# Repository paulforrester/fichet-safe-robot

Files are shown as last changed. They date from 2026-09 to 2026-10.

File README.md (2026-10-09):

# Fichet-Bauche "Complice" Safe — Combination Robot

> **Revision 2026-10-09.1** · all four drivers on the RAMPS (key in E0); UART pigtail replaces the hub board · log: `docs/revisions.md`

An automated device to determine the combination of an unmarked
Fichet-Bauche "Complice" safe found in the house at 6 Rue du Mulet,
Bordeaux. The project spans three phases: mechanical (tube-socket
coupler and drive), electrical (motor/servo control circuitry), and
firmware/code (dial indexing and combination search).

## Status

Mechanical phase. Tooth geometry is **CLOSED** (see `docs/decisions.md`
for how we got here):

| Dimension | Value | Status |
|---|---|---|
| Tooth height (radial, root→tip) | 2.00 mm | **locked in** — see `docs/decisions.md` |
| Tooth width (tangential) | 1.04 mm | **locked in** |
| Tooth depth (axial, into socket) | 5.0 mm | measured directly off the real key |
| Tip diameter | 7.73 mm (measured), 7.38mm printed (0.35mm clearance) | working |
| Collar diameter | 11.75 mm | confirmed, clears the ~12mm door recess |

Housings: the **dial unit v2** (`cad/dial_unit_housing.scad`, geared, on 608
bearings — door-pattern test passed on the real door) and the **key turner v1**
(`cad/key_turner_housing.scad`, slotted cap over the key's bow, motor on the key
axis — print `print_key_fit_test.scad` first). Both attach to the door with
22mm rubber-coated M4 pot magnets (6 + 3) held by printed retainers
(`print_magnet_retainer.scad`) — pull-test one on the door when they arrive. See `docs/housing_decisions.md` and `control/sequence.md`.

Electronics ordering is done — four orders placed 2026-09-29 cover
essentially the full `docs/bom.md`, tracked there against every line.

**How to build and run it:** `docs/manual.md` (mechanical and electrical
assembly, building and uploading the firmware, operating and monitoring).

## Repo layout

- `CLAUDE.md` — context and working rules for Claude sessions (cloud or
  local): project facts, decisions, open issues, how Paul works.
- `cad/` — OpenSCAD source for 3D-printed parts.
  - `tube_socket_test_key.scad` — the confirmed spline/tooth geometry,
    parametric (tooth height, width, and an engraved label are all
    top-level variables — see the file header for CLI override examples).
  - `common_mounts.scad` — shared NEMA17 bolt pattern, rubber-magnet
    mount (`rmag_*`), and D-shaft coupler-bore modules, used by both housings below.
  - `dial_unit_housing.scad` / `key_turner_housing.scad` — the two
    mounting housings (see `docs/housing_decisions.md`). The dial unit is
    v2 (geared); `dial_unit_assembled.scad` shows it assembled and the
    `print_*.scad` wrappers export each printable part.
  - `cad/tools/` — `dial_layout_check.py` (clearances, gear mesh, axial
    stack, read straight from the SCAD) and `dial_interference_check.py`
    (3D overlap check of the whole assembly through its range of motion).
  - `cad/sketchup/` — the build script for a SketchUp review model of the
    dial unit (run through the SketchUp connector; the SCAD files are what
    gets printed).
  - `cad/renders/` holds reference renders and STLs of specific
    iterations.
- `docs/` — dimensional decisions (`decisions.md` for the test key,
  `housing_decisions.md` for the housings), the bill of materials
  (`bom.md`, tracked against actual orders), terminology reference, and
  reference photos (`docs/photos/`).
- `control/` — control architecture and operating sequence
  (`sequence.md`), the wiring harness (`wiring.md`, diagrams in
  `control/harness/`, including the printable `schematic.pdf`), the firmware (`control/firmware/`), the bench
  bring-up plan (`bringup.md`) and the lock research (`lock_research.md`).

## Terminology

Tooth dimensions are described consistently as WIDTH (tangential),
HEIGHT (radial), DEPTH (axial into the socket) — see
`docs/tooth_terms_diagram.png`.

## Next steps

- Bench-fit the v0.1 housings once printed; confirm the placeholder
  dial-hole spacing and key-bow clamp range against the real door/key
  (see `docs/housing_decisions.md`'s "Bench-fit TODO").
- Dial unit v2 (geared, 608 bearings — see `docs/housing_decisions.md`):
  print the door-pattern test (`cad/print_dial_pattern_test.scad`) and the
  three gear-shafts first, and check them on the real door, before the
  big parts. Springs ordered (arriving 2026-10-07).
- Wiring harness designed (`control/wiring.md`; **revision 2026-10-08.1**:
  all four drivers on the RAMPS, the key in the E0 socket, no remote board
  or signal cable); firmware written and host-tested (`control/firmware/`,
  v0.4); next: the bench bring-up (`control/bringup.md`).

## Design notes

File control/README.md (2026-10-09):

# Control (motors, drivers, wiring, firmware)

> **Revision 2026-10-09.1** · key driver on the RAMPS E0 socket; UART pigtail · log: `../docs/revisions.md`

- `sequence.md` — control architecture and the operating sequence (seat,
  home, learn the key's stop angle, the 8,000-combination loop, false sets),
  plus what the firmware decided on top of it.
- `wiring.md` — the wiring harness: pin map, driver jumpers and UART
  addresses (all four drivers on the RAMPS, key in E0), the UART pigtail
  (the UART junction), the key motor cable, motor currents, power-up
  order, shopping list, with sources.
- `harness/ramps_and_uart.md` — one bench sheet of everything fitted to the
  RAMPS, and the UART pigtail.
- `harness/` — the printable schematic, WireViz harness diagram, Graphviz
  overview and the UART pigtail drawing (sources + rendered SVG/PNG).
- `firmware/` — Arduino Mega sketch (TMCStepper), its plain-C++ core with
  host tests against a simulated lock, and the serial logger. See
  `firmware/README.md`.
- `bringup.md` — bench bring-up in seven stages, with what to send back.
- `lock_research.md` — does the Complice relock or lock out? (No evidence of
  an attempt lockout; a relocker fires on attack.)

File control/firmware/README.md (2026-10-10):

# Firmware — Fichet safe robot (Mega 2560 + RAMPS 1.4 + 4 × TMC2209)

> **Revision 2026-10-09.1** · key driver on the RAMPS E0 socket; firmware v0.4 (unchanged by 2026-10-08.2) · log: `../../docs/revisions.md`

Implements the sequence in `control/sequence.md` on the pin map in
`control/wiring.md`. Bring it up on the bench with `control/bringup.md`.

## v0.4 (2026-10-08, project revision 2026-10-08.1): key driver on RAMPS E0

The key's TMC2209 moved from a remote board at the key turner to the RAMPS
**E0** socket (`control/wiring.md`, log 2026-10-08). For the firmware:
- `pins.h`: key STEP **D26**, DIR **D28**, EN **D24** (Marlin `pins_RAMPS.h`
  E0_STEP/DIR/ENABLE); DIAG stays on **D19** (Z_MAX S).
- The key is now an ordinary axis: direction from its DIR pin and enable from
  its EN pin, like the dials. Gone: `setKeyShaft()` (GCONF.shaft written and
  read back before each key move), the TOFF = 0 disable, and the `DIR` error
  that reported a shaft read-back failure.
- **Safer at power-up**: RAMPS pulls every EN line high (10 kΩ), so the key
  driver now stays off until the firmware enables it. Before, its EN was tied
  low and it switched on with 12 V at its pot current.
- Verified: host tests 53/53 (~36,500 checks), logger tests 3/3, AVR build
  52.1 KB flash. Not run on hardware.

## What it does

1. **Session start** (on `start`, `resume`, or the button; ~40 s), in order:
   - ping all four drivers over UART (version 0x21, right address) and
     configure them;
   - home the key against its rest stop (searching up to 180°: the key stays
     wherever it was left);
   - **calibrate the key** (see Calibration below);
   - seat the dials: slow, bounded 1/8 turn clockwise. The dials turn
     clockwise without limit, so this never meets a stop;
   - **calibrate each dial** with one free clockwise turn;
   - home each dial anticlockwise on its stop, in two passes that must agree,
     and park it on its first click;
   - learn the key's stop angle **N** (3 tries, median, spread checked).
2. **Attempt loop** over the 8,000 combinations in serpentine order: each
   attempt moves **one dial by one position**, never wraps a dial, turns the
   key to N + 15°, and logs the **actual angle reached**. It classifies the
   attempt (clean / false set / success / early), retracts the key to its
   rest stop, and saves progress to EEPROM.
3. **Every 200 attempts, a re-check**: re-home every dial (the home must be
   where the step count says it is) and re-learn N at the last clean fail.
   If anything moved, it stops, **rewinds to the last good re-check**, and
   asks for a re-seat.
4. **Success** (key gets ≥ N + 10°): stops, holds the key where it got to, and
   prints the combination as positions 1–20: clicks counted clockwise from
   each dial's stop (there are no marks on the door). The success is saved in
   EEPROM. The key stays turned after `release` (it doesn't spring back), so
   take the key turner off and pull the key to open the door, as the manual
   says.
5. **Resumable**: progress is in EEPROM. After a power cut or a re-seat,
   `resume` (or the button) redoes the session start and continues from the
   last re-checked index (≤ 200 attempts redone). A pause runs a re-check
   first, so a resume after a pause loses nothing.

## Calibration (Paul's suggestion, 2026-10-06)

The robot measures its own StallGuard thresholds and finds the clicks,
instead of relying on hand-tuned numbers. The datasheet recommends this kind
of in-application threshold rather than a fixed one (§11.4, p. 59).

- **Each dial**: one free turn clockwise (1¼ turns with the ramps). The
  dials turn clockwise without limit, so nothing is pressed. Every
  cruise-speed SG_RESULT reading is binned by its place within a click (20
  full steps = 18°).
  - **Threshold**: the lowest bin mean is the dial's heaviest free-running
    load. SGTHRS is set so a stall reads at **50 %** of it
    (`CFG_SG_CAL_PCT`; stall = SG_RESULT ≤ 2·SGTHRS, datasheet §5.3).
  - **Clicks**: their ripple has an 18° period, and its fundamental gives
    where the clicks are. Model: turning clockwise, the click spring helps
    just before a notch (SG highest) and resists just after (SG lowest), so
    the notch is a quarter click after the SG peak. After homing, position 1
    is the first click at least 3 full steps clockwise of the stop. Later
    sessions keep the same numbering, using the offset stored in EEPROM.
  - If the ripple is too weak to trust (amplitude < 3, or < 2× the
    residual), it falls back to `CFG_HOME_OFFSET_x` and says so.
- **Key**: from rest, 60° clockwise (its stop is at ~100°); median SG →
  threshold. It then goes back to rest by stalling on the rest stop **with
  the new threshold**, which proves the threshold works.
- The last calibration is kept in EEPROM. The next session needs it for its
  very first move (homing the key) before it re-calibrates.
- `calibrate` does all of this as a separate step and prints `CAL` /
  `OFFSET` lines. Run it once, with the key turned back to its start by hand.
  `set autocal 0` / `set detentcal 0` switch either part off (then `sgX` /
  `offX` are used as set).
- **ASSUMPTIONS to check on the bench** (`control/bringup.md` stages 3–4):
  - that 50 % sits safely between free running and a stall;
  - that the click ripple is visible in SG_RESULT at all.

StealthChop tunes itself during the first moves after power-up (datasheet
§6, AT#1/AT#2, p. 38: up to ~400 full steps at 60–300 RPM). The calibration
turn — 500 full steps at 1 rev/s motor — gives it that before anything
depends on StallGuard.

Every move has a step bound and a timeout. Stalls are caught on the DIAG
interrupt. `!` on the serial line aborts the current move and switches all
drivers off. Dials never move while the key is out of rest. A run refuses to
start until the key has a threshold (from `calibrate`, or `CFG_SGTHRS_KEY`).
No move starts on a driver that has reset (next section).

## Driver resets (GSTAT check, v0.3, 2026-10-07)

**The problem.** A TMC2209's logic runs from VS (12 V) through its own
regulator, not from VIO (datasheet §2.2, p. 10; `control/wiring.md` §3.5). If
VS or VIO dips, the chip resets to its power-on registers (§17, p. 74). Here
that could be a loose 12 V terminal, a driver loose in its socket, or a 5 V
glitch. (Until revision 2026-10-08.1 the key driver's 12 V also ran through
the hub's fuse holder and the inter-unit cable; both are gone.) After a
reset (datasheet pp. 9, 22–23, 28–29, 32):
- `SGTHRS` and `TCOOLTHRS` are 0: no StallGuard, no DIAG pulse;
- the current comes from the VREF pot (`I_scale_analog` = 1), with `IRUN` = 31;
- the microsteps come from MS1/MS2: 1/8, 1/32, 1/64 and 1/16 for A, B, C and the key;
- `CHOPCONF` = 0x10000053, so the power stage is on (TOFF = 3);
- the motor pulls to the driver's power-on electrical position, up to
  ±2 full steps away (§3.6.1, p. 15).

Only `GSTAT.reset` (bit 0) shows that it happened. v0.2 set the drivers up
only during the session start (and at each bench command), and read GSTAT
only in `ping`.

**The worst case in v0.2** (kept as history: in v0.4 `setKeyShaft()` is gone,
so this exact path no longer exists, but any reset still runs the driver on
its power-on registers until the GSTAT check below catches it; traced from the datasheet defaults and the
TMCStepper 0.7.3 source; not tried on hardware): the key driver resets
between two key moves.
- Before each key move, `setKeyShaft()` calls `shaft()`, and TMCStepper
  writes the whole GCONF from its own copy. That sets `I_scale_analog` back
  to 0, so the current no longer comes from the pot: `IRUN` = 31 is ~1.8 A RMS
  with the 0.11 Ω sense resistors. It also selects the MRES register, still at
  its reset value of 1/256 step.
- So the key turns under 10° instead of N + 15°, open loop, and never stalls.
- `reached` is then the commanded angle, and `classify()` returns SUCCESS.
  The run stops on a false success, holding the key.

The simulator reproduces the false success
(`control_unseen_key_reset_gives_a_false_success`). A dial driver that
resets moves its dial by the wrong amount until the next re-check fails on
homing. That costs time, but `resume` rewinds, so it doesn't give a wrong
result.

**What v0.3 does** (all in `src/core/robot.cpp`, through `Hal::gstat()`):
- **Before and after every move**, it reads the moving driver's GSTAT
  (`doMove`). Nothing moves on a driver that has reset. A reset during a move
  is seen before the move's result is used: a key try is classified only
  after its "after" check.
- **At the start of every attempt** (and of a bench `try`), it reads all
  fitted drivers. That covers the dials that don't move in that attempt.
- **Before re-writing a driver's settings** while the robot still relies on
  them, it reads that driver first, because `configure()` clears GSTAT. In
  the session start, `calKey`, the seat and the dial calibration each set the
  drivers up again.
  - The first setup after power-up or a release (pause, error, `release`)
    clears the power-on flag, which is expected (`control/bringup.md`
    stage 1). So a 12 V cycle while paused is not an error.
  - On the bench, a command after switching 12 V off and on without
    `release` stops once with `DRVFAULT`, which is true: the positions are
    gone.
- **On a flag** (1 reset, 2 drv_err, 4 uv_cp) or **no answer** (80), it
  logs `GSTAT,ms,axis,gstat,when` and stops with `ERR,…,DRVFAULT`. In a
  run, it first rewinds to the last re-check, as a failed re-check does.

**Why stop, instead of re-running `configure()` and re-homing.**
- It's how every other hardware fault is handled (DRIVER, CONFIG, DIAG,
  JAM, TIMEOUT): drivers off, an ERR line, Paul fixes the cause, `resume`.
  Only EARLY retries, and it stops after three.
- A reset means a supply dropped out: a contact fault, which will
  probably come back, perhaps worse. Carrying on would hide it.
- After a reset the positions are lost, not just the settings. Steps sent
  while the driver was down did nothing, and the motor may have jumped 2 full
  steps. Recovering needs the key and every dial re-homed and N re-learned.
  That is exactly the session start `resume` runs. Doing it automatically
  would duplicate that path inside the attempt loop, for a rare fault.
- The rewind costs at most 200 attempts (~3 min). It happens at the stop, so
  it doesn't depend on `CFG_RESUME_FROM_CHECKPOINT`. The attempt in progress,
  or the one before it (an idle dial is only checked at the next attempt),
  may have run with a driver that had reset.

**Cost**:
- 10 GSTAT reads per attempt: 4, then 2 for each of the 3 moves. A
  TMCStepper read waits 2 ms twice, so that is about 45 ms per attempt, ~5 %,
  or ~6 min over all 8,000.
- +0.9 KB of flash.

**Limits**:
- A reset *during* a move shows only at the move's end. Until then the move
  runs open loop, at the VREF-pot current and other microsteps. The longest
  such moves are the dials' homing passes: up to 1.15 dial turns towards the
  stop. So every driver's pot now goes to minimum (`docs/manual.md` 2.3;
  before, only the key's did). Then a driver that resets has next to no
  torque until the check.
- `uv_cp` isn't latched (datasheet p. 24). A short dip that switches the power
  stage off without resetting the chip shows only if a read happens during
  it. The step it may cost is what the re-checks are for.
- The datasheet routes the power-on reset to DIAG too (Fig. 15.1). That isn't
  relied on.

**Bench check**: `control/bringup.md` stage 6, step 6 (12 V off and on, then
a move must stop with `DRVFAULT`).

## Files

| Path | What |
|---|---|
| `safe_robot/safe_robot.ino` | setup/loop: serial lines, button, LED |
| `safe_robot/config.h` | **every unmeasured value, in one block** (directions, currents, speeds, StallGuard thresholds, home offsets, key home mode, classification bands, re-check interval) |
| `safe_robot/pins.h` | pin map (= `control/wiring.md` §1) |
| `safe_robot/hw_mega.{h,cpp}` | thin hardware layer: TMCStepper setup, step pulses, DIAG interrupt latches, non-blocking SG_RESULT reads, EEPROM, USB serial |
| `safe_robot/src/core/` | **plain C++, no Arduino**: sequencer (`robot`), calibration (`calib`, `calstore`), serpentine order (`combo`), step ramp, classification, EEPROM journal, TMC UART frames, log-line builder |
| `test/` | host tests (`make -C control/firmware/test`): unit tests + whole runs against a simulated lock (`sim_hal.h`) |
| `tools/logger.py` | serial → raw log + attempts CSV; `--analyse` re-classifies offline |
| `Makefile.mega` | command-line AVR build (how the cloud session checks it compiles) |

## Build and flash (Paul, Arduino IDE)

1. Arduino IDE → Tools → Manage Libraries → install **TMCStepper** by
   teemuatlut (**0.7.3**). SPI, SoftwareSerial and EEPROM come with the IDE.
2. Open `control/firmware/safe_robot/safe_robot.ino`.
3. Tools → Board: **Arduino Mega or Mega 2560**; Processor: **ATmega2560**;
   Port: the Mega's USB port. Upload.
4. Close the IDE's Serial Monitor before using `tools/logger.py` (only one
   program can have the port). Or use the Serial Monitor at **115200**, line
   ending **Newline**.

## Library choice: TMCStepper 0.7.3

- It drives the TMC2209 over a shared hardware UART with per-driver addresses
  (`TMC2209Stepper(Stream*, R_SENSE, address)`). That's exactly our bus.
- Its read handles the single-wire echo: it skips bytes until the reply header
  `0x05 0xFF <register>` (replies go to master address 0xFF, datasheet p. 19).
  It also checks the CRC and retries (`TMC2208Stepper::_sendDatagram()` /
  `read()`).
- It exposes everything we need: `rms_current()` (datasheet current formula
  with the 0.11 Ω sense resistors), `SGTHRS`, `SG_RESULT`, `TCOOLTHRS`,
  `toff`, `GSTAT`, `IOIN`, `senddelay` (and `shaft`, used until v0.3).
- Marlin 2.0.x — which runs TMC2209 over UART on RAMPS/Mega boards —
  depends on exactly this version (`ini/features.ini`: `HAS_TRINAMIC_CONFIG =
  TMCStepper@~0.7.3`, branch head 743d310). Marlin 2.1.x now builds against its own fork,
  MarlinFirmware/TMCStepper 0.8.9 (`ini/features.ini`). The fork's changes
  since 0.7.3 are about other chips/platforms, plus a longer TMC2208 read
  timeout. Our 115200-baud reads finish well inside 0.7.3's.
- 0.7.3 is what the Arduino Library Manager installs.
- Alternative considered: janelia-arduino/TMC2209 (TMC2209-only, maintained).
  It would also work; TMCStepper won on its RAMPS/Marlin track record.
- Not used for motion: the firmware makes its own step pulses (a plain
  trapezoid in `core/ramp`). That keeps every move bounded, lets it stop on
  the first DIAG pulse, and lets it read SG_RESULT between steps without
  blocking. AccelStepper would hide those.

## Serial commands (115200 baud, newline)

| Command | What |
|---|---|
| `help`, `status`, `cfg` | list commands; state + progress; current settings |
| `ping` | query all 4 drivers: `DRV,axis,present,version,ms1,ms2,diagPin,diagIoin,gstat,ifcnt` |
| `start` | new run from combination 0 (refuses if a run is stored or StallGuard isn't tuned) |
| `resume [force]` | continue a stored run (`force` if position settings changed) |
| `pause` (or the button) | finish the current attempt, re-check, switch drivers off |
| `!` | abort the current move at once, drivers off |
| `release` | all drivers off (also lets go of the key after a success) |
| `reset yes` | erase stored progress |
| `calibrate` | key (from its start position) + seat + one free turn per dial + homing; prints `CAL`/`OFFSET`, saves to EEPROM |
| `seat`, `home [A\|B\|C]`, `learn` | bench: run one part of the session start |
| `goto a b c` | bench: dials to positions (1–20) after `home` |
| `try` | bench: one key attempt at the current dial setting |
| `key <deg>` | bench: turn the key clockwise up to `deg` (stops on stall), then back |
| `jog <A\|B\|C\|K> <fullsteps>` | bench: bounded move (±800 full steps), stops on stall |
| `sg <A\|B\|C\|K> <fullsteps>` | bench: like jog, printing `SG,axis,fullstep,value` samples |
| `set <name> <value>` | bench, RAM only: `sgA..sgK`, `maA..maK`, `rps100A..K` (speed × 100), `invA..K`, `offA..C`, `keyhome`, `margin`, `success`, `clean`, `early` (0.1°), `recheck`, `seatma`, `seatrps100`, `sgmin100`, `autocal`, `detentcal`, `calpct` |

The button: pauses a running session; when idle, resumes a stored run or
starts a new one.

## Log lines (what `tools/logger.py` reads)

```
ATT,ms,index,a,b,c,keySteps,keyDeg,stalled,sgMin,class,nDeg     one per attempt
SUCCESS,ms,index,a,b,c,keyDeg,doorA,doorB,doorC
HOME,ms,dial,pass,distFull,stalled,sgMin     LEARN,ms,try,keySteps,keyDeg,stalled,sgMin
NSTOP,ms,keySteps,keyDeg,spreadDeg           RECHECK,ms,index,dial,discrepancyFull,nDeg,ok
CAL,ms,axis,baseline,sgthrs,amp,resid,clicksTrusted    OFFSET,ms,dial,offsetFull,fromClicks
GSTAT,ms,axis,gstat,when     a driver reset or fault, just before ERR DRVFAULT (see "Driver resets")
EV,ms,name,detail    ERR,ms,code,text    DRV,...    CFG,...    SG,...    # human text
```

`GSTAT`: `gstat` is hex: 1 = the driver reset, 2 = drv_err (overtemperature
or short), 4 = uv_cp (12 V too low), 80 = no answer; flags add up. `when` is
`before` or `after` (a move of that driver), `attempt` (the check of all
drivers before each attempt), or `config` (before its settings are written
again).

`a,b,c` are positions 1–20 counted from each dial's home stop. `keyDeg` is
measured from the key's rest stop. `class` is CLEAN / FALSESET / SUCCESS / EARLY. The raw angle is always logged, so classes can be redone afterwards:

```
python3 control/firmware/tools/logger.py --port /dev/tty.usbmodemXXXX
python3 control/firmware/tools/logger.py --analyse runs/<stamp>_attempts.csv
```

The first is live mode (type commands in it); the second re-analyses a run.

## Verified here (cloud session, no hardware)

- **Host tests**: `make -C control/firmware/test` — 53 tests, ~36,500 checks,
  0 failures. Built with `-Wall -Wextra -Werror` (g++ 13 and clang 18) and
  also run under AddressSanitizer + UBSan. They cover:
  - the serpentine order: a bijection, and each step moves one dial by one
    position;
  - the ramp, classification, the EEPROM journal (rotation, torn write), TMC
    CRC (cross-checked against TMCStepper's own) and the reply parser (echo,
    noise, bad CRC);
  - whole runs against the simulated lock: finds the combination; false sets
    logged and skipped; power loss + re-seat → resume; a dial slip caught by
    the re-check and rewound; pause/resume; untuned / missing driver / no hard
    stop / no key rest stop / DIAG stuck high / abort / repeated early stops;
    the combination at index 0; settings changed between sessions; a too-dull
    StallGuard fails safe; N is never learned on a false set; dials that turn
    clockwise without limit and stop anticlockwise (as Paul found), with the
    seat never pressing a stop; a power cut leaving the key at its ~100° stop;
  - driver resets (v0.3): a key reset during a key try stops the run with
    `DRVFAULT`, rewound, and no false success, and `resume` then finds the
    real combination. A control, with the reset hidden as in v0.2, shows the
    false success. Also covered: a key reset during a dial move stops it
    before the key turns; an idle dial's reset is caught before the next
    attempt moves anything; a reset before a settings rewrite is reported, not
    wiped; a driver that stops answering mid-run stops it; a bench command
    after an unreleased 12 V cycle reports it once; a 12 V cycle while paused
    is not an error; one attempt costs 10 GSTAT reads;
  - calibration: thresholds from the measured load; the click centre
    recovered from a noisy ripple at any phase and any start position;
    clicks placed anywhere relative to the stop (with a control showing the
    fixed config offset would miss them); no visible ripple → config
    fallback; readings too low → error; `calibrate` → stored → used after a
    power cycle; numbering kept stable across sessions;
  - the simulator also polices the firmware: no dial moves with the key out,
    every move bounded and with a timeout, never a move on a disabled driver,
    never a move on a driver that has reset, never pressing into a stop with
    stall detection off, current never above 1.2 A.
- **Logger**: `python3 -m pytest control/firmware/tools` (3 tests). A
  simulated full run (`make -C control/firmware/test simlog`, 1,787 attempts)
  replays through `logger.py`, and its offline classes match the firmware's on
  every attempt.
- **AVR build**: compiles for the ATmega2560 with avr-gcc 7.3 + Arduino AVR
  core 1.8.6 + TMCStepper 0.7.3 (Ubuntu packages; the Arduino download
  servers are blocked here): 52.1 KB flash (19.9 %), 1.4 KB static RAM
  (16.6 %), no warnings from this code (v0.4, 2026-10-08).

**Not verified**: anything on hardware. The simulator's lock is my model of
the description in `control/sequence.md` and Paul's checks, not the real lock;
in particular its StallGuard click ripple is an assumption. Motor
directions, how SG_RESULT really looks on these dials, the 50 % threshold
rule and speeds are unknown until `control/bringup.md` is done.

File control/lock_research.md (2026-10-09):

# Does the Fichet-Bauche "Complice" relock or lock out after wrong tries?

> **Revision 2026-10-09.1** · project revision baseline (this research is unchanged by the wiring changes) · log: `../docs/revisions.md`

Researched 2026-10-06 (cloud session), for the `control/sequence.md` open
item "anti-manipulation relocking behaviour, before running thousands of
automated attempts". Updated the same evening with the manual's own "Normal
use" text (a screenshot from Paul) and Paul's checks on the real key.

## Answer

**No source I could find says the mechanical Complice counts wrong attempts,
adds penalty delays, or locks out.** What it does have is a **relocker
("délateur")** that blocks the lock *for good* when it is **attacked
mechanically or with heat**. So the risk to manage is force, not the number
of tries: never hammer or over-torque the key. The firmware is already built
that way. Confidence: medium-high. The manual's normal-use procedure
(below) has no limit on tries or waiting time. Paul has read the manual: it
has **no warning about entering wrong combinations** (2026-10-06). The
relocker details come from search-result excerpts (the pages are blocked
from this session) and describe the *current* Complice.

**New point from the manual — to check before the long run:** in normal use
you **set the combination first, then insert the key**. The robot keeps the
key inserted, at rest, while it turns the dials. Paul (2026-10-06): the
dials turn with the key at its start, and still click with the key turned to
its ~100° stop. Paul's two cautions (possibilities, no source):
- The lock might let the bolts retract only if the key has gone back to the
  start since the combination was set. Firmware v0.2 returns the key to its
  rest stop after every attempt, so it doesn't depend on this.
- The lock might only count a combination dialled with the key *out*, as
  in the manual. The dials turning with the key in doesn't rule this out.
  If it's true, the robot can't open the safe without a way to pull the key
  out and push it back in at every attempt. There's no bench test I know of
  that settles it short of finding the combination. Stage 4b.6 gives a weak
  hint, and the first full run is the real test.

Searched again 2026-10-06 (evening) for how the 3-tube combination and the
M3B key interact: nothing found. Fichet's manual PDF and the patent sites
are blocked from the cloud session. A search excerpt mentions a separate
Fichet "3-tube combination" user manual; Paul may have it.

## What the sources say

**0. The Complice manual, "Opening the safe" page, NORMAL USE** (screenshot
from Paul, `docs/photos/complice_manual_normal_use.png` — primary source):

> **Opening the combination**: Dial the combination - Insert the key into the
> M3b lock and turn it clockwise - Pull on the key to open the door.
> **Closing - Locking**: Close the door - Turn the key anticlockwise to engage
> the bolt - Remove the key - Scramble the combination.

- No limit on tries, and no waiting time, in normal use.
- Order: combination first, then the key (see the new point above).
- Clockwise opens; anticlockwise engages the bolt, and the key comes out only
  then. That matches Paul's checks (2026-10-06): the key goes in one way only;
  from there it won't turn anticlockwise at all; it turns ~100° clockwise to
  its stop; it can only be removed back at the start position.
- "Pull on the key to open the door": the robot only turns the key. On a
  success it holds the key where it got to; Paul takes the key turner off and
  pulls.
- This manual calls the key lock "M3b"; current sales pages say "MxB" or
  "MPx" — a different generation, probably.

Points 1–6 are quoted from search-engine excerpts. The pages themselves could not be
opened from here, so I couldn't check which sentence is on which page: treat
the links as where to look. Paul can open them.

1. **Lock = key lock + 3-counter mechanical combination, 8,000
   combinations.** "The MPx lock is systematically associated with the three
   Fichet-Bauche counter tube combination in Complice safes. The 3-counter
   combination offers up to 8,000 possible combinations." That matches our
   20 × 20 × 20. Retailers list the model as "Complice … Mxb & 3 Tubes".
   [lacledu16.fr](https://lacledu16.fr/en/products/complice-20l),
   [fichet-bauche.com Complice](https://www.fichet-bauche.com/product/complice-safe-40l-2/),
   [domoowe-coffre-fort.fr](https://www.domoowe-coffre-fort.fr/shop/coffre-fort/coffre-fort-a2p-classe-0/coffre-fort-fichet-bauche-complice-20-mxb-3-tubes/)
2. **Relocker triggered by attack.** "A relocking device blocks the lock
   definitively in the event of a mechanical or thermal attack"; "a délateur
   … that blocks the lock definitively in case of mechanical or thermal
   attack". Same sources, and
   [coffre-fort.com, Fichet AF II with MxB + 3 tube counters](https://www.coffre-fort.com/armoires-fortes-af2/2613-armoire-forte-fichet-af-ii-250l-serrure-mxb-3-tubes-compteurs.html).
3. **Anti-forget key retention**: "an anti-forget mechanism retains the key
   until the lock is locked". This only means the key can't be pulled out
   while the lock is open. It doesn't affect the robot.
4. **The manual** (Complice Installation and Use Manual, 94 pages,
   [ManualsLib 1388230](https://www.manualslib.com/manual/1388230/Fichet-Bauche-Complice.html))
   has sections "Opening the safe", "Setting the combination", "Checking the
   setting", "Scrambling the combination", "Troubleshooting". One excerpt:
   to change the combination, "Lock the MPX lock by turning the key
   counterclockwise and remove the key", then turn a change button inside the
   door. That fits Paul's observation: the key turns **clockwise** to open.
5. **Certifications**: A2P / EN 1143-1 for the safe; mechanical combination
   locks of this class are tested to EN 1300, which includes **manipulation
   resistance**. That's about not leaking the combination by feel (relevant
   to false sets), not a lockout feature.
   [BSI, EN 1300](https://knowledge.bsigroup.com/products/secure-storage-units-classification-for-high-security-locks-according-to-their-resistance-to-unauthorized-opening)
6. Fichet-Bauche patents on safe combination locks from the 1970s exist
   (FR2337241 "Serrure à combinaisons pour coffre-fort ou analogue",
   CA1066079). They might describe the counter mechanism of an older safe
   like this one; I couldn't open them (patents.google.com blocked).

## What this means for the robot (already in the firmware)

- **Limited force**: the key runs at ~2× the torque it takes to turn by hand
  (bench stage 5) and stops at the first StallGuard pulse. Dials run at
  ≤ 1 A. Nothing is hammered or retried at higher force.
- **If the relocker ever fired**, the key would most likely stop somewhere
  new, or not turn. The firmware notices: an attempt that stops well short of
  N is retried, and after 3 in a row it stops (`ERR EARLY`). The re-check
  every 200 attempts stops if N has moved (`ERR RECHECK`). Either way it
  stops and waits for Paul, with the log showing where it changed.
- **Every attempt's angle is logged**, so false sets (the fence dropping
  partway) can be told apart afterwards (`tools/logger.py --analyse`).

## Worth doing by hand before the long run (Paul)

1. Done (Paul, 2026-10-06): the manual has no warning about wrong
   combinations.
2. **With the key inserted at rest, can each dial still be turned by hand
   with the tube key?** If not, the robot as designed can't work: it can't
   take the key out between tries. Done (Paul, 2026-10-06): yes, at the
   key's start, and they still click with the key at its ~100° stop.
3. With the dials at some setting, turn the key to its stop by hand, with
   normal force, 10 times. Does anything change (stop angle, feel, a click)?

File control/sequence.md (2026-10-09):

# Control architecture and operating sequence

> **Revision 2026-10-09.1** · key driver on the RAMPS E0 socket; UART pigtail (no change to the sequence) · log: `docs/revisions.md`

Working notes on how the robot actually operates the safe, so this
doesn't only live in chat. Captures the mechanism understanding and
the operating sequence as of 2026-09-29 — expect this to get refined
once tomorrow's measurements and the first hardware tests come in.

## The mechanism

This is a classic wheel-pack combination lock, not a front-dial
combination safe:

- 3 "dial" sockets (the tube-socket spline our test key fits) each
  drive one combination wheel directly.
- A 4th socket takes the real opening key. Turning it drives a cam
  against a fence that rides on the edges of the 3 wheels.
- Wrong combination: the fence rides on the wheel edges, and the key
  stops after some angle, call it N°.
- Right combination: all 3 wheels' gates align under the fence, it
  drops in, and the key turns past N° (roughly N + 10%, though this
  margin may need empirical tuning — see False sets below) into the
  bolt-withdraw motion.
- Each dial wheel has 20 positions → 20³ = 8,000 combinations to
  search. Very tractable to brute-force.

## Hardware: one answer for "force feedback" on all 4 motors

Force/torque feedback is needed in two places, both solved by the
same component:

1. **Homing each dial wheel** — move backward until resistance is
   felt at position 1 of 20 (assumes each wheel has a natural hard
   stop just past position 1 — **needs verification against the real
   lock**, see open items below).
2. **Not overdriving key 4** — back off as soon as resistance is felt,
   whether that's the normal N° stop or (hopefully) further in on a
   winning combination.

**Recommendation: stepper motors + StallGuard-capable drivers
(TMC2209 or TMC2130)**, one per motor (4 total). These sense
back-EMF and report when a motor is being blocked — no separate
torque sensor, load cell, or current-sense board needed. Well
supported on both Arduino (step/dir + UART for the stall threshold)
and Raspberry Pi, ~€3-5/driver.

For key 4's rotation angle: counting steps from a freshly-established
home (re-homed at the start of every attempt, per the sequence below)
should be accurate without an encoder, as long as the printed coupler
doesn't slip under torque. A cheap magnetic encoder (AS5600) is an
easy add-on later if slip turns out to be a problem. Note for later:
if an encoder is added and full rotation could exceed 360°, it needs
turn-counting logic — a bare AS5600 only reports position within one
revolution.

## Electronics: Mega 2560 + RAMPS 1.4 wiring plan

Settled 2026-09-29. Mounting/wiring the 4 drivers: **RAMPS 1.4**, a
shield that plugs directly onto the Mega 2560 and has 5 driver sockets
in the same StepStick footprint as the BigTreeTech TMC2209 V1.3 boards
— no soldering needed for the 3 local drivers, they plug straight in.
Only 3 of its 5 sockets get used (X/Y/Z, for the 3 dial motors) — the
key-turner unit's driver does **not** plug into the shield, per the
driver-placement rule above; it's wired out to the remote unit over the
inter-unit cable instead.

**Correction (revision 2026-10-08.1, 2026-10-08):** the key driver now plugs
into the RAMPS **E0** socket too, so all four drivers are on the shield. The
remote board and the inter-unit signal cable are gone; only the key motor's
own cable runs to the key turner. See the "Cable and driver placement"
correction below and `control/wiring.md` (log 2026-10-08).

**Correction to the earlier "4 hardware UART ports" plan**: the Mega
has 4 hardware serial ports total (`Serial`/`Serial1`/`Serial2`/`Serial3`),
but `Serial` (pins 0/1) is tied up by USB — using it for a driver would
mean losing USB programming/debug output while the robot runs. That
leaves only 3 clean hardware UARTs, not 4. Fixed by using the TMC2209's
built-in **UART multi-drop addressing** instead of 1:1 dedicated lines:
up to 4 drivers can share a single UART bus, each given its own address
(0–3) via its MS1/MS2 pin strapping. So **all 4 drivers (3 local + the
remote key-turner) share one bus on `Serial2`** (Mega pins 16 TX / 17
RX). This is the officially-supported mode, not a hack, and it means
only one UART signal wire needs to extend out to the remote unit rather
than a dedicated pair.

Why `Serial2` specifically, not `Serial1` or `Serial3`: confirmed
against the standard RAMPS 1.4 pin map — `Serial1` (pins 18/19) and
`Serial3` (pins 14/15) are the *same physical Mega pins* as the Z-axis
and Y-axis MIN/MAX endstop headers respectively. Using either of those
serial ports would make the corresponding endstop headers unusable.
`Serial2` (pins 16/17) has no such conflict, so it leaves every
endstop header free.

That matters because the endstop headers are being **repurposed to
carry each local driver's DIAG (stall-output) signal** instead of an
actual mechanical switch — X_MIN (pin 3), Y_MIN (pin 14), Z_MIN (pin
18), one per local dial motor's driver. With UART on `Serial2`, none of
these three are double-booked.
**Correction (2026-10-06, `control/wiring.md`):** the DIAG lines go to
X_MIN (D3), **X_MAX (D2)** and Z_MIN (D18) for dials A/B/C, and the key's
DIAG to Z_MAX (D19). DIAG is a *pulse* (TMC2209 datasheet §11.2), so the
firmware latches it with an interrupt, and Y_MIN's D14 has no external
interrupt on the Mega. Y_MIN now takes the start/stop button.

*(Superseded by revision 2026-10-08.1: the key driver is in the RAMPS E0
socket, so its STEP/DIR/EN come from E0 — D26/D28/D24 — and its DIAG lead
goes to Z_MAX like the dials', with no cable. The paragraph below is kept as
the earlier remote-driver plan.)*

For the remote key-turner driver (off-shield): STEP/DIR/ENABLE + its
DIAG line are wired from 4 free Mega digital pins (exact pins aren't
critical — any spare GPIO broken out on RAMPS' AUX headers or tapped
from the Mega's own header row works) out through the inter-unit cable,
alongside the shared `Serial2` UART tap and 12V/GND motor power. Each
driver (all 4) also needs a ~1kΩ resistor between the MCU's UART TX pin
and its own PDN_UART pin — standard TMC2209 single-wire UART wiring,
one resistor per driver regardless of bus-sharing.

**Correction (2026-10-06, `control/wiring.md`):** (1) one 1kΩ resistor in
total, not one per driver: TX2 → 1kΩ → bus, RX2 and every driver's
PDN_UART straight on the bus — the datasheet's own circuit (TMC2209 DS
Fig. 4.1). (2) The key-turner driver gets only STEP (D23), DIAG (D19),
UART, 12V, GND and 5V over the 6-conductor cable; its EN and DIR are tied
to GND on its board, and the firmware disables it and sets its direction
over UART (CHOPCONF.TOFF, GCONF.shaft).

## Mounting: two independent units, not one frame

Resolved 2026-09-29: photos confirmed the keyhole (socket #4) and the
3-dial cluster are visibly separated on the door face — not adjacent.
Socket #4's key also turned out to use a traditional ornate bow, not
the spline profile (see below), which is a second, independent reason
to decouple it. **Building this as one rigid frame spanning the whole
door was dropped** in favor of two independently-mounted units,
connected by a cable:

- **Dial unit**: all 3 dial-socket motors + drivers, the
  microcontroller (Arduino/Pi), and the power supply. This is the
  "brain" — it's the side with 3 motors and the actual combination
  logic, so centralizing electronics here avoids a third enclosure.
- **Key-turner unit**: a single motor + local driver + a gripper that
  clamps onto the real key's bow (already manually inserted into
  socket #4 before the robot goes on — this unit never touches the
  key's blade, just its protruding head). Connected to the dial unit
  by a cable.

Each unit attaches to the door independently with **neodymium magnets**
— confirmed 2026-09-29 that both the safe body and door are ferrous, so
this is settled, not a fallback. Paul already has ~100 2mm×8mm
neodymium disc magnets on hand from a prior print project ("Poop chute
print for h2d"), which also worked out a tight-press-fit pocket size for
this exact magnet: **8.00mm diameter × 1.9mm depth** (0.1mm undersize on
depth vs. the 2mm-thick magnet, for an interference press fit rather
than a loose slot — glue optional/backup, not load-bearing). Reuse that
pocket geometry directly in both units' mounting faces rather than
re-deriving it. **Superseded 2026-10-06:** both units now mount with
22mm rubber-coated M4 pot magnets (Wukong) — 6 on the dial unit, 3 on the
key turner — in through holes with printed retainers; the disc pockets
printed with strings and bare discs grip poorly sideways. See
`docs/housing_decisions.md`. Splitting avoids one large frame needing to be
dimensionally accurate across the full door width, and each unit is
small enough to print in one piece.

**Cable and driver placement**: originally each driver sat next to its
motor — the key driver on a remote board at the key turner — on the
reasoning that "StallGuard reads back-EMF right at the motor, and long
motor-phase wiring would dull that sensitivity".

**Correction (revision 2026-10-08.1, 2026-10-08):** that reasoning is
withdrawn. StallGuard is measured inside the driver, and sensorless homing
is routinely done with the driver on the mainboard and the motor on a cable
of this length (e.g. 3D printers; Klipper's TMC documentation). So the key
driver moves to the RAMPS **E0** socket like the dials, and the key motor's
own ~1 m cable runs to it. The 6-conductor signal cable, the remote board
and its Phoenix connectors are gone. If bench stage 5 shows the key's
StallGuard too dull through the cable, shorten it. Full reasoning:
`control/wiring.md`, decision log 2026-10-08.

**Alignment**: the key-turner unit has an easier mounting job than the
dial unit — since the real key is already seated in socket #4 by hand
(step 1), the gripper only needs to land on the key's protruding bow,
a much bigger and more forgiving target than the ~8mm star holes the
dial unit has to register precisely.

## Dial drive (v2 housing, 2026-10-05)

Each dial is driven through a **2:1 spur gear pair** (14T on the motor,
28T on the dial shaft): one dial turn = 2 motor turns = 400 full steps =
**20 full steps per dial position**. Motor direction is reversed relative
to the dial (external gears). The gear-shaft is **spring-loaded**: when the
unit is put on the door, a plug that doesn't line up with its star is
pushed back, so the first job of every session is a "seat" routine —
turn each dial motor slowly (at most 1/8 of a dial turn = 45deg of dial,
90deg of motor) until its plug drops into the star, then home as below.
Until the dial torque is measured, run the dial drivers at about 1A RMS:
the reduction doubles what the motor can put into the printed gear and
plug teeth.

**Key torque (measured 2026-10-06): 0.07–0.08 N·m** (0.14–0.16 kg at
50mm). About a quarter of what the motor gives at ~1 A, so the key turner
stays direct drive. Run the key motor at reduced current (~2× the key's
torque) and stop on StallGuard at the end stop, so the drive doesn't push the
housing against its magnets harder than it needs to.

## Operating sequence

1. Real key inserted into hole 4 (manual, one-time per session).
2. Dial unit aligned over the 3 dial holes and attached to the door;
   key-turner unit aligned over the protruding key bow and attached
   separately; the two connected by cable.
3. Dialing process triggered (code or a physical switch, TBD).
4. Each dial key homes: drives backward until stall-detected
   resistance = position 1 of 20. Can run serially or in parallel
   across the 3 dial motors.
5. Key-4 motor calibrates baseline: turns until stall-detected
   resistance (= N°), notes the angle, retracts to start. This
   replaces any need to pre-measure N by hand — the robot learns it
   as its first task, every session.
6. Main loop, for each of the 8,000 combinations:
   a. Drive each of the 3 dial wheels to the target digit.
   b. Attempt to turn key 4 to N + margin°.
   c. Record the *actual angle achieved* (not just pass/fail — see
      False sets below), whether by reaching target or by stalling
      first.
   d. Retract key 4 to start.
   e. If achieved angle clears the success threshold: stop, report
      the combination.

### As implemented (firmware v0.1, 2026-10-06 — `control/firmware/`)

Decisions made while writing the firmware, on top of the sequence above:

- **Start (step 3)**: both — the serial command `start` or the push button
  (on RAMPS Y_MIN). The button also pauses a run and resumes a stored one.
- **Order of the 8,000**: serpentine. Consecutive attempts differ in one dial
  by one position, so each attempt turns one dial one click, and no dial ever
  wraps from position 20 back to 1 (a wheel with a hard stop couldn't).
- **Key home every attempt**: retract until the key stalls at its rest
  (anticlockwise) stop, so every angle is measured from the same point.
  The rest stop exists: the key can't turn anticlockwise from where it goes
  in (Paul, 2026-10-06). A config switch can make the key return by step count
  instead. Paul also found (2026-10-06) that the dials still click with the
  key left at its ~100° stop, so the key wouldn't *have* to come all the way
  back between tries. **Kept anyway (Paul, 2026-10-06)**: see "Return the key
  to rest every attempt, or park it near N?" under Open items.
- **Self-calibration (v0.2, 2026-10-06, Paul's suggestion)**: each session
  measures each motor's free-running StallGuard reading and sets its own
  stall threshold (stall = reading down to 50 % of it). Each dial makes one
  free clockwise turn for this. From the same turn's 18° click ripple it
  finds where the clicks are, so position 1 = the first click clockwise of
  the stop. Where the first click sits relative to the stop can't be measured
  by hand (Paul: evenly spaced, 18° apart). The key is measured over 60° of
  free travel from rest. Datasheet §11.4 recommends this kind of
  in-application threshold. Bench stages 3–4 check the assumptions (the
  50 % rule; the ripple being visible).
- **Key home search 180°** (was 30°): the key stays wherever it is left — it
  doesn't spring back (Paul, 2026-10-06). After a power cut mid-attempt it
  can sit at its ~100° stop, and the session start must find the rest stop
  from there before any dial moves.
- **Seat**: turns each dial 1/8 turn slowly **clockwise**, the direction in
  which the dials never meet their stop. (Changed 2026-10-06 after Paul's
  check: the first version turned toward the stop.)
- **Homing (step 4)** runs twice per dial (stall, back off 2 positions, stall
  again); the two must agree. Before homing, the key is homed, then the slow
  1/8-turn seat runs.
- **N (step 5)** is the median of 3 tries. It is learned at the most recent
  attempt that was a clean fail — never at a possible false set. On a fresh
  run it's learned at the first two combinations, keeping the lower.
- **Each try** drives the key to N + 15°: clean ≤ N + 4°, false set between,
  success ≥ N + 10°, "early" < N − 8°. All are config values, to be set from
  the measured spread. The raw angle is always logged.
- **Re-check every 200 attempts**: re-home the dials (the stall must come
  where the step count says) and re-learn N. On a mismatch (a unit slipped),
  stop and rewind to the last good re-check.
- **Resume after power loss** (or a re-seat): progress lives in EEPROM. A
  resume redoes the whole session start and restarts from the last good
  re-check (≤ 200 attempts redone). A pause re-checks first, so it loses
  nothing.
- **Results reach Paul** as USB serial lines. `tools/logger.py` saves a raw
  log and an attempts CSV, and can re-classify afterwards.

## False sets

Some wheel-pack locks have false sets — positions that let the fence
drop partway, allowing a bit more rotation than a clean wrong
combination but not full opening. Purely a software concern, no
hardware implication. Logging the actual degrees achieved on every
attempt (not just a boolean) means the data can be re-examined after
the fact to tell clean-fail / false-set / success apart, rather than
depending entirely on getting the threshold right on the first pass.

## Open items

Resolved 2026-09-29:
- [x] Socket #4's profile — **not the spline at all**. The real key
      has a traditional ornate bow; the key-turner unit grips that
      bow rather than replicating a blade. See Mounting above.
- [x] Tooth geometry — locked in at HEIGHT 2.00mm / WIDTH 1.04mm, see
      `docs/decisions.md`.
- [x] Socket recess / collar clearance — measured directly at 12.25mm,
      confirms the 11.75mm collar (0.5mm clearance) is fine as-is.
- [x] One frame vs. multiple units — going with two: dial unit
      (3 motors + electronics) and key-turner unit, cabled together.
- [x] Ferrous door confirmed (both body and door) — mounting is
      neodymium magnets, pocket geometry reused from a prior project
      (8.00mm dia × 1.9mm depth for 2mm×8mm disc magnets, press fit).
      ~100 magnets already on hand.
      **Changed 2026-10-06** to 22mm rubber pot magnets (6 + 3), ordered —
      measure them and do a one-magnet sideways pull test on arrival.

Still open:
- [x] Key / lock-hole measurements (Paul, calipers, 2026-10-06): lock hole
      12.05mm; key protrudes 31.89mm, 84.75mm long, turns clockwise ~100deg
      then stops; bow vertical at rest, 24.60 wide, 2.5-2.9 thick on its flat
      part, swelling 9.48 at ~8mm, ring hole 10.75. Key turner v1 grips it with
      a slotted cap (see `docs/housing_decisions.md`). Torque to turn: measure
      with the fit-test lever + a luggage scale.
- [x] Lock hole position relative to the dial cluster — **calipers
      2026-10-06**: top-left dial->lock 110.13mm (far 122.25 / near
      98.01), bottom dial->lock 126.95mm (far 139.4 / near 114.5).
      Trilaterated against the dial triangle: the lock sits **~125mm to
      the left of the dial-cluster centre, essentially level** (1.8mm
      low), matching the door photo. The dial plate is r75, so ~50mm of
      clear door between the plate edge and the lock hole — the two
      units sit side by side with room. Cable run between them ~125mm.
- [x] Center-to-center spacing between the 3 dial holes — **measured with
      calipers 2026-10-05**: isosceles, 33.0mm across the top pair, 42.5mm
      from each to the bottom hole (apex down). Holes 13.0mm dia; the
      star starts 3.14mm below the door face (a real key goes in to
      15.5mm; the slots narrow toward a point, so a 2mm depth gauge
      stops at 8.92mm). In
      `cad/dial_unit_housing.scad` (v2); the 36mm equilateral placeholder
      was wrong by up to ~5mm. See `docs/housing_decisions.md`.
      (Superseded by the caliper measurement above — the old ~55mm
      photo estimate for the dial-to-lock gap was low; it's ~125mm
      centre-to-centre.)
- [x] Verify each dial wheel has a hard stop near position 1, for the
      homing move in step 4 to find — **Paul, 2026-10-06**: each dial turns
      clockwise without limit and stops when turned anticlockwise; 20 clicks
      per turn. Homing is anticlockwise to that stop. The seat turn was
      changed to clockwise so it can never press into it. Still to measure:
      the angle from the stop to the first click (home offset, bringup 4a).
- [x] Where the first click is relative to each dial's stop — Paul
      (2026-10-06): can't be read by hand, but the clicks are evenly spaced,
      18° apart; no marks on the door. The firmware now finds the clicks
      from StallGuard each session (v0.2). Key: stays wherever it's left (no
      spring back).
- [x] Do the dials still turn with the real key inserted at rest? The
      manual's normal use dials the combination *before* inserting the key
      (`docs/photos/complice_manual_normal_use.png`); the robot keeps the
      key in throughout. **Yes (Paul, 2026-10-06): the dials turn with the
      key at its start position, and still click with the key turned to its
      ~100° stop and left there.**
- [ ] **Does a combination dialled with the key already in count?** (Paul,
      2026-10-06.) The dials turn and click with the key in, but nothing
      shows that they still set the wheels then. The manual dials *before*
      inserting the key. If the lock only checks a combination set with the
      key out, the robot as designed can never open it, and it would need
      to pull the key out and push it back in at every attempt (a mechanical
      redesign of the key turner). No source either way: searched
      2026-10-06, but Fichet's manual PDF and the patent sites are blocked
      from the cloud session. A search excerpt mentions a separate Fichet
      "3-tube combination" user manual. How we'll know:
      (1) bench stage 4b.6 compares the dials' calibration with the key out
      and in: a clear difference is a warning sign, while the same numbers
      are only weak reassurance;
      (2) the first full run is the real test (≤ ~2 h of motion).
      If it ends with no success and clean data, this is the first suspect.
- [x] Return the key to rest every attempt, or park it near N? Raised by
      Paul's check above (2026-10-06). Firmware v0.2 returns it to its rest
      stop every attempt, which re-zeroes the angle each time and matches the
      manual's sequence. Parking it ~10° short of N between tries would save
      time. **Estimate** (motion only, from `config.h` speeds and the
      firmware's own ramp code; not measured): a full return costs ~0.82 s
      per attempt (key out 0.30 s + back 0.30 s + one dial click 0.23 s), so
      ~1.8 h for all 8,000. Parked: ~0.34 s, ~0.75 h. That saves ~1.1 h in
      the worst case, ~0.5 h on average. Logging, EEPROM writes and the
      re-checks every 200 attempts are not included; they're the same either
      way. Risks of parking: (1) Paul's caution: the lock may need the key
      back at the start before the bolts can retract. If so, the right
      combination would look like a clean fail, and we'd only find out
      after a whole run without success. (2) The angle would come from step
      counting since the key last touched its rest stop, so a lost step
      would shift later readings until the next re-zero. Recommendation:
      keep the full return for the first full run. Revisit if stage 6 shows
      attempts much slower than this estimate. **Decided (Paul,
      2026-10-06): keep the full return.**
- [ ] Torque/effort needed to turn each dial wheel and the key, to
      size motors and gearing.
- [x] Whether the Fichet-Bauche "Complice" line has any known
      anti-manipulation relocking behavior — **researched 2026-10-06**,
      `control/lock_research.md`. No source mentions an attempt-counting
      lockout. A relocker ("délateur") fires on mechanical or thermal attack,
      so forces stay low. The firmware stops if the key's stop angle changes.
      Confidence medium: only search excerpts were readable from the cloud
      session. Paul to read the manual's "Opening" / "Troubleshooting" pages.

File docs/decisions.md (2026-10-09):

# Tube-socket test key — dimensional decision log

> **Revision 2026-10-09.1** · project revision baseline (mechanical log; not affected by the wiring changes) · log: `./revisions.md`

Working notes on how the test key's dimensions were arrived at, most
recent first. Terminology (WIDTH / HEIGHT / DEPTH) is defined in
`tooth_terms_diagram.png` in this folder.

## CLOSED — tooth geometry locked in: HEIGHT 2.00mm, WIDTH 1.04mm

Printed a second height-sweep plate (1.80 / 1.85 / 1.90 / 1.95 /
2.00mm, all at width 1.04mm). All five felt equivalent by hand on the
bench, so going with **2.00mm height / 1.04mm width** — the tightest
of the batch, on the reasoning that a snugger fit means less slop
under repeated motorized engagement, which matters more for wear than
it does for one-off hand testing.

Open concern, not a geometry problem: repeated engagement may wear the
printed teeth over the ~8,000-combination search. Two mitigations,
both deferred to when the final motorized coupler (not this hand-test
key) is built:
- Print the final coupler in a tougher material than plain PETG —
  PETG-CF or nylon.
- The StallGuard-based force-feedback motor control (see
  `control/sequence.md`) backs off at first resistance rather than
  grinding, which should wear the teeth less than hand-forcing did
  during testing.

This closes the tooth-geometry tuning item. `cad/tube_socket_test_key.scad`'s
top-level `tooth_height`/`tooth_width` defaults should be updated to
2.00/1.04 the next time that file is touched.

## v0.4 — width corrected to 1.04mm

Re-measured tooth WIDTH on the real key with calipers: 1.04-1.06mm, not
the 1.0mm used through v0.3. Height stays at 1.75mm (the v0.3 winner).
Printed and labeled "1.75" / "1.04" (two lines) on the bottom of the
handle. Width is still printed at the full measured value with no
clearance subtracted, same as every round so far. Pending: fit report
from the bench. If still loose, 1.06mm (top of the measured range) is
the next step, before touching height again.

## v0.3 — height made a direct parameter, tested 1.65 / 1.70 / 1.75mm

HEIGHT (radial, root→tip) had been DERIVED as
`(tip_dia - root_dia) / 2` from two directly-measured diameters,
giving ~1.4mm. That print clicked the dials but had noticeable
rotational play. Rather than trust the derived value further, height
became a directly-settable parameter, with root_dia computed FROM it.
Tip diameter (7.73mm measured) was deliberately held fixed — it
governs whether the part fits in the socket bore at all, and was
already working — so only the root was adjusted (deepening the valley
between teeth), which can only improve engagement, not risk making the
part too big to insert.

Printed three variants on one plate (1.65 / 1.70 / 1.75mm), each
labeled on the bottom of the handle with its own height value.
**1.75mm won** — most reliable click, least play of the three.

## v0.2 — root cause: photo-derived bore diameter was wrong by ~50-60%

The original socket bore diameter (12.5mm) came from pixel-measuring
the socket in macro photos (ruler-tick calibration, Hough circle fit
on the bore). That print came out geometrically correct relative to
what was modeled (normal ~0.3mm PETG shrink) — the print pipeline was
never the problem. The INPUT was wrong: direct calipers on the real
key read 7.73mm tip-to-tip and 4.94mm hub-to-hub, both ~60% smaller
than the photo estimate. Likely cause: ruler px/mm miscalibration, or
the Hough fit locking onto a chamfer/counterbore ring rather than the
true bore. Replaced all bore-diameter-derived parameters with direct
caliper measurements.

Also fixed in this round:
- Stacking order bug: the registration collar (wider than the bore)
  was ahead of the teeth, so the collar hit the door face before the
  teeth could reach the socket. Fixed to plug → collar → handle.
- Tooth profile: rebuilt as a single closed polygon tracing the whole
  star outline (not a union of per-tooth wedges sharing a center
  point) — the shared vertex was silently corrupting the STL export
  even though the OpenSCAD preview looked correct.
- Handle lengthened to 32mm (from a 9mm robot-coupling stub) so it can
  be gripped and turned by hand for bench testing.

## Measured directly off the real key (calipers), unchanged since v0.2

- 8 teeth, evenly spaced 45° apart
- Tip-to-tip (major) diameter: 7.73mm
- Tooth depth (axial, pre-taper section): 5.0mm
- Collar clearance: door recess measures ~12mm; collar set to 11.75mm

## Fit clearance

`fit_clearance = 0.35mm` (total diametral/radial clearance) has been
unchanged since v0.2 and was never the source of the reported play —
it applies to the tip/root diameters, not to tooth width. Tooth width
has always been printed at the full measured value with zero
clearance subtracted.

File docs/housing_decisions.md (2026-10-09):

# Housing — design decision log

> **Revision 2026-10-09.1** · project revision baseline (mechanical log; not affected by the wiring changes) · log: `./revisions.md`

Working notes on the two 3D-printed housings (`cad/dial_unit_housing.scad`,
`cad/key_turner_housing.scad`), most recent first. Companion to
`docs/decisions.md` (tube-socket test key geometry) and
`control/sequence.md` (control architecture) — this file covers the
mechanical housings that carry that geometry onto the actual door.

## 2026-10-09: start/stop button mount on the electronics deck (revision 2026-10-09.1)

**Paul's design** (2026-10-09): the 7mm momentary button goes in from **under**
the deck. Its body's wide base (measured **9.36mm**) sits in a **10mm x 2.5mm
recess** in the deck's underside, the thread goes up through a 7mm hole, and
the 1.05mm washer (OD 10.07mm) and nut (11.3mm across corners) go on top.
The thread is only ~6mm long and the deck is 5mm thick; the recess leaves a
2.5mm web, so 3.5mm of thread is above the deck. Its leads (soldered, heat
shrink) run under the deck and come up through a **4mm wire hole** next to
the RAMPS endstop block. Where (Paul): left of the Mega/RAMPS, near the deck
leg that the base plate doesn't cover; the wire hole midway between the
base plate's edge and the deck's edge, beside the endstop block.

**Placed** (`button_pt`, `wire_hole_pt` in `dial_unit_housing.scad`; top
view: `docs/photos/deck_button_mount_topview.png`):
- Button at (-54.4, 28.0): 16mm from `deck_leg_pts[2]` (-50.5, 43.5), the
  only leg outside the base plate. Searched over the deck for the point
  nearest that leg that keeps the recess >= 2mm from the deck edge, the nut
  clear of the leg's M6 head (r 7) and of the base plate, and the body (r 5)
  >= 6mm from every motor can in plan view: the body hangs below the deck
  and the cans are only `deck_clearance` = 6mm under it.
- Hole 7.4mm (7mm thread + 0.4, the same clearance as `m6_clear_d`);
  recess 10mm (Paul's number) x 2.5mm.
- Wire hole 4mm at (15.65, -47.06): on the line from the endstop block
  straight out past the board's digital-header edge, 6mm out from the base
  plate's edge. **Assumption:** the base plate's outline is only known from
  its overall size, 114 x 57.5mm (SparkFun community forum, see the
  2026-10-04 entry), with its end flange at the jack end; good to maybe
  +/-2mm here. The deck there was only ~7.6mm wider than the plate, too
  tight for a 4mm hole, so the deck outline gets a small lobe (r 5.5)
  around the hole.
- The endstop block's position comes from the RAMPS 1.4 KiCad layout
  (`matt3u/RAMPS-1.4_KiCad` `ea33bdf`, Mega footprint U1 as the frame).

**Printing:** the deck prints mating face down, so the recess is a 10mm
pocket on the bed face; its 2.5mm ceiling bridges 10mm around the 7.4mm
hole (short spans, no supports).

**Checked:** new `cad/tools/button_mount_check.py` (reads the SCAD's LAYOUT
echo; slices the rendered deck): recess wall to deck edge 3.3mm; nut to the
nearest M6 head 3.3mm; nut to the base plate ~27mm; body to the motor cans
5.9mm beyond its radius; wire hole wall to the deck edge 3.5mm and to the
base plate (estimate) 4.0mm; slices show the 10.0mm recess and the 7.4mm and
4.0mm holes at the right places; deck STL watertight, 1 body.
`dial_layout_check.py` ALL PASS, `dial_interference_check.py` NO
INTERFERENCE; `dial_unit_housing.stl` still 9 watertight bodies.

**VERIFY (Paul):** the switch body's length below the deck clears the motor
can (plan-view gap 5.9mm beyond the body's radius); the nut and washer
start on the 3.5mm of thread; the wire hole is clear of the base plate's
real edge.

## 2026-10-07 (later): magnet holes now 21.7 mm, from the fit test

**Fit test (Paul, `cad/magnet_fit_test.stl`):** the 21.5 mm magnets fit
snugly in the **21.8** hole and can be worked into the **21.7** hole. Paul's
call: 21.7, so the rubber grips and the magnet can't slide out of the inner
side. **Split sleeves** (`magnet_split_sleeves.stl`): only the two thickest
(0.55, 0.60 mm) printed; the thinner walls didn't come out. Not pursued:
the plates are reprinted instead.

**Change:** `common_mounts.scad` `rmag_d` = 21.5 (measured), `rmag_hole_d` =
21.7 (from the test, no longer derived from `rmag_d`). Same seat ring (OD
29), same retainer (it now bears on the ring from 21.7 to 27 mm). Both
SketchUp build scripts updated to match.

**Fitting changes with a snug hole:** the magnet no longer drops onto its
retainer, so its depth is set by how far it's pressed in. The manual (§1.3a)
now presses each magnet in from the door side with the plate's inner face on
the table: the table stops the magnet's back level with the ring top.

**Checked:** re-rendered `dial_front_assembly.stl`, `key_turner_base.stl`
and the two whole-unit STLs, all watertight. Sliced at 2.5 mm: six 21.70 mm
holes in the dial plate, three in the key-turner base. Volume up by 0.84 and
0.42 cm³, exactly the plastic the smaller holes add.
`dial_layout_check.py` ALL PASS (unchanged margins: the ring is the same);
`dial_interference_check.py` and `key_turner_check.py` NO INTERFERENCE.

**Magnet height (Paul, same day): 6.0–6.1 mm**, most of the spread in the
rubber; the threaded back is **flush** (no boss). So the rubber stands
**0.2–0.3 mm proud** of the door face, inside the 0.1–0.5 mm the design
allows: no CAD change (`rmag_h` stays 6). A flush back means the retainer
sits flat on the magnet's steel.

**Still not measured:** thread depth (sets the M4 screw length).

**Wrap strips** (`magnet_wrap_strips.stl`, Paul's idea): flat PLA strips,
69 × 5 mm, 1, 2 or 3 layers (0.2/0.4/0.6 mm), to wrap round a magnet in the
*old* 22.4 mm holes. The gap there is 0.45 mm a side, so the 2-layer strip
is the nominal match. A fallback for the plates already printed.

**Result (Paul, same evening): the strips work, and the 2-layer (0.4 mm)
one is "perfect".** Paul is printing a full set and **keeping the plates he
already printed (22.4 mm holes)**, to save the plastic. So the build as it
stands is **22.4 mm holes + a 2-layer wrap strip on each magnet**. The
21.7 mm holes stay in the CAD as the design for any future reprint, which
then needs no strips.

## 2026-10-07: door magnets fall out of the inner side — holes to become a snug fit

**Finding (Paul):** the Wukong magnets measure **21.5 mm**, not the listed
22 mm, so they're loose in the 22.4 mm holes. On the door that doesn't
matter: the pull holds each magnet's retainer on its seat ring. Off the
door, with the unit on its side, a magnet and its retainer slide out of
the inner side of the hole.

**Design flaw (mine, 2026-10-06 entry):** the retainer is screwed only to
the magnet, never to the plate. It stops the magnet moving *toward* the
door; nothing stops it moving the other way.

**Fix:** keep the retainer for the door's pull, and make the hole grip the
rubber so the magnet can't slide inward. How tight a printed hole comes out
depends on the printer, so `cad/magnet_fit_test.stl` has five holes, 21.4 to
21.8 mm, at the real depth (5 mm plate + 0.8 mm ring). Paul picks the
smallest one a magnet presses into by thumb and that holds it upside down;
that diameter becomes `rmag_hole_d` for both plates (dial front assembly,
key-turner base), then re-render, re-run the checks, reprint. Height and
thread depth still to be measured (they set the proud face and the screw
length).

**Retrofit for the plates already printed (Paul's idea, same day):** a thin
split sleeve in each 22.4 mm hole (`cad/magnet_split_sleeves.stl`, walls
0.40/0.45/0.50/0.55/0.60 mm, identified by 1–5 nicks). Relaxed OD 22.0 so it
drops in; the magnet opens the slit until the sleeve meets the hole wall,
then squeezes the rubber. Grip needs 21.5 + 2 × wall > the printed hole
(true 22.4 → wall over 0.45). Full hole length, no flange: a flange on the
ring top would lift the retainer and pull the magnet face back into the
plate. If it works, the sleeve can become a split skirt on a reprinted
retainer.

## 2026-10-07: printed holder for the interim 5 × 20 mm fuse (hub F1)

Paul's spec (2026-10-07): one 5 × 20 mm glass fuse, 1.6 A T, in series in a
12 V line under 0.6 A, 20 AWG wire each end; metal-to-metal contact on each
end cap with a force that doesn't depend on the plastic holding its shape
(PETG creeps); no screw point on the glass, no solder on the caps; swap
without tools or with a screwdriver; live parts covered; labelled
"1.6 A T"; perfboard or inline mount; PETG or PLA. Why it's needed:
`control/wiring.md`, log 2026-10-07.

**Design** (`cad/fuse_holder.scad`, print `cad/print_fuse_holder.scad` →
`cad/fuse_holder.stl`):
- **End A, fixed:** an M3 heat-set insert through a 4mm wall, its front face
  flush with the fuse cradle; the fuse cap bears on the brass. Its rear end
  stands 1mm proud into the clamp pocket, so the wire clamp is
  head → washer → wire → brass, with no plastic in the clamp.
- **End B, sprung:** a second insert, *not* heat-set, slides loose as a brass
  piston; its front face bears on the B cap and the B wire is clamped to its
  rear face the same way. One QUARKZMAN 0.5 × 7 × 20 spring (a spare from
  the dial-unit pack) pushes on that washer: 16.5mm long with the fuse out,
  **13mm working (7mm compressed, ≈1.8–2.8 N at the BOM's estimated
  0.25–0.4 N/mm)**, 11mm when the fuse is pushed back to lift it out. The
  spring carries no current (the wire is clamped to the piston), and
  7mm of spring travel makes plastic creep irrelevant to the force.
- **Swap:** slide the lid out by its end flap, push the fuse 2mm toward the
  spring, lift it out; reverse to fit. No tools.
- **Covered:** the lid slides in grooves and stops on end wall B; its flap
  covers the hex-key hole at end A (the A screw head behind it is live).
  Wires leave through notches at each end. Label "1.6 A T" engraved in the
  lid.
- **Prints with no supports or bridges:** every channel is open to the top
  and closed by the lid. Body base-down, lid label-down.
- **Size:** 54.5 × 18.8 × 12.2mm (28.7 wide over the tabs). That's longer
  than the ~50 × 30mm hub board, so mount it **beside** the hub board (four
  tabs, M3 or 3mm zip ties) or inline in the wire, not on the board.

**Printed (Paul, 2026-10-07): "came out beautifully."**

**Checked:** `cad/tools/fuse_holder_check.py` — body, lid, fuse, both
contacts, both screw stacks and the spring, pairwise with manifold3d with the
fuse in, pushed back 2mm, and out: no overlaps; fuse touching both contact
faces when in; body and lid watertight. Asserts in the SCAD: the M3x6 can't
poke out of the insert's front face (it stops 0.5mm short), engages ≥ 3.5mm,
and the spring stays clear of solid when loading.

**Not verified — measure before printing:** insert OD and length (BOM: "4.2mm
OD, ~5mm"; if shorter than 5mm, the M3x6 would reach the fuse — change
`ins_l`); M3 washer size (7 × 0.5 assumed); the spring's coil count (solid
length must stay under 11mm). The heat-set hole is 4.0mm; open it up if the
insert won't go in cleanly.

**Assembly:**
1. Heat-set one insert into wall A from the clamp pocket side, until its
   front face is flush with the cradle face.
2. Strip ~10mm of the A wire, lay it in the end-A notch, wrap it clockwise
   round an M3x6 under an M3 washer, thread it into the insert's rear end
   with your fingers, then tighten with a 2.5mm hex key through the end hole.
3. Piston: wrap the B wire the same way under a washer on the second insert's
   rear end (M3x6); tighten in your fingers/with pliers on the insert.
4. Drop the spring into the spring channel, the piston in front of it, and
   lay the B wire in its side slot and groove to the end-B notch.
5. Push the piston back, lower the fuse into the cradle, let it go. Slide the
   lid in from end A until it stops.
6. Before powering: continuity end to end through the fuse with the
   multimeter, and tug each wire.

## 2026-10-06 (evening): assembly order written up in `docs/manual.md` §1.4–1.6

The print notes at the end of `cad/dial_unit_housing.scad` point to "the
bottom of the v2 entry" for the dial unit's assembly order, but that entry
has none. The manual now gives one, **derived from the CAD, not yet tried**:
magnets → bearings → gear-shafts → motors on the sled (their screws go in
from the sled's inner face, so before the sled meets the front) → pinions →
springs → sled onto the front legs → deck → Mega base plate (deck first: two
of its M6 screws sit under the base plate, 2026-10-04 entry). The magnets go
first because they sit under the sled's outline. The key turner's order is
the one in `cad/key_turner_housing.scad` (motor → hub → plate onto legs),
with the magnets first. Paul to correct either from the real build.

Also noted there:
- the cap's tongue sits in a through-groove, so it may slide out while the
  unit is being placed; if it does, the cap goes on the bow first.

Paul's answers, same evening:
- **Key-turner plate screws: M6 × 16, not M6 × 20.** He has both and found
  the 16 mm work better. That gives 10 mm of thread in the 16 mm pilot,
  the same as the dial unit. The print note in `cad/key_turner_housing.scad`
  is corrected (a comment only; no geometry change), and `docs/bom.md`
  lists them.
- **Slicer:** Bambu Studio's default settings for the H2D, for every part so
  far.
- **Springs:** ordered, arriving 2026-10-07.

## 2026-10-06: key fit test passed; key torque 0.07–0.08 N·m — direct drive is fine

**Fit test (Paul, `key_fit_test.stl`, cap in PETG-CF):** the cap slides onto
the bow without forcing, sits with the key tip just short of the slot bottom,
and turns the key to its stop. Cap geometry confirmed as designed.

**Torque:** luggage scale in the lever hole (50mm from the axis) read
**0.14–0.16 kg** to turn the key: × 9.81 × 0.050 = **0.069–0.078 N·m**.
(Correction: first reported as 1.4 kg, a misread decimal — Paul caught it
the same day. The 1.4 kg version had concluded the motor was too weak and
needed a 4:1 reduction; that conclusion is withdrawn.)

**Motor:** the 17HE19-2004S is rated 0.59 N·m holding at 2.0 A; running
torque is lower and falls with speed, and at the ~1 A the drivers are
planned to run at, expect roughly 0.3 N·m. That is about 4× the key's
torque, so **v1's direct drive stays** — no gearing.

**Housing / magnets:** whatever turns the key pushes back on the housing.
While turning: 0.078 N·m ÷ 0.031m (magnet circle radius) = 2.5 N (~0.26 kgf)
across 3 magnets, ~0.09 kg each — small. The bigger load is at the key's
end stop, where the motor pushes with everything it has until it is
stopped: at full 2 A that could approach 0.59 N·m (~0.65 kg per magnet).
So run the key motor at reduced current — enough for ~2× the key's torque
— and stop on StallGuard at the end stop; that keeps the stop load to a
fraction of what the magnets need to hold anyway. Still confirm with the
one-magnet pull test.

## 2026-10-06: both units mount with 22mm rubber-coated pot magnets (Wukong)

**Why.** Two problems with the 2mm×8mm press-fit disc field: (1) Paul found
strings on the floors of the printed pockets — a floor printed as the first
layer over a pocket can't be cleaned out reliably, so the discs wouldn't seat
flat; (2) on a vertical door what holds the unit up is sideways (shear) grip,
not straight pull. Published supplier figures put a bare neodymium magnet's
shear grip at roughly 15% of its pull, and a rubber-coated pot magnet's at
roughly 31–38% (e.g. a 22mm rubber magnet listed 5.9 kg pull / 1.8 kg
shear). Rubber also won't scratch the door. Paul ordered Wukong 22mm
rubber-coated magnets with an M4 threaded back, listed 6mm tall
(Amazon.fr B0DGQ52DY9 20-pack / B0D5B4TJ7B 10-pack). The listing gives no
pull rating, so the real number comes from a test on the door.

**Mount (shared, `rmag_*` in `common_mounts.scad`).** A 22.4mm **through**
hole — nothing is printed over air, so there's no floor to string. On the
plate's inner face a seat ring (OD 29) stands up to z = 5.8 from the door
face; a printed retainer disc (Ø27 × 3, `print_magnet_retainer.scad`) sits on
the ring and an M4 screw goes through it into the magnet's back. The ring top
sets the depth, so every magnet's rubber stands exactly 0.2mm proud of the
door face, and the door's pull goes magnet → screw → retainer → ring, not into
a press fit. Change `rmag_d` / `rmag_h` if the real magnets differ from the
listing; everything else follows.

**Dial unit.** 6 magnets at r = 53.5mm, first at 26.75°, 60° apart — radius
and rotation brute-force searched for clearance to the three front legs and
the bearing bosses (the first try, r57 / 25°, hit a leg by 0.24mm). The 8×2
disc-pocket field is gone. The plate now rests on the rubber, 0.2mm off the door,
so the dial plugs sit 0.2mm shallower in the stars (3.7 instead of 3.9mm):
not worth anything else changing. `dial_layout_check.py`: seat ring to front
legs 2.39mm, to bearing bosses 2.43mm, 7.0mm inside the plate rim, 24.5mm ring
to ring — ALL PASS. `dial_interference_check.py` (magnets + retainers added as
a part): NO INTERFERENCE.

**Key turner.** 3 magnets at r = 31mm, at 60/180/300° (between the legs); the
legs were re-clocked from 180/60/−60° to 0/120/240° to make room. That puts
one leg toward the dials, but legs sit inside the round base (r36 < r43), so
the footprint on the dial side is unchanged; the base only bulges past r43
where the magnet rings are (to r46.5), and the magnet at 180° is the one
facing away from the dials. Base plate 6 → 5mm to match the dial plate (the
ring adds the other 0.8mm). Asserts: ring to leg ≥ 1.5mm (actual 13.3), ring
to key opening ≥ 1.5mm (actual 2.5). `key_turner_check.py` with magnets added:
NO INTERFERENCE at all 15 poses.

**Load.** Dial unit ~1.3–1.5 kg on 6 magnets, key turner (lighter, one
motor) on 3. Not verified: no pull/shear figure exists for these magnets.
**Test before trusting it:** stick one magnet to the door and pull sideways
(parallel to the door) with the luggage scale. 1.5 kg on six magnets is
0.25 kg each; wanting about 3× margin for the motors' reaction torque and
vibration, if one magnet slips under ~0.8 kg sideways, add magnets or a floor
leg before running the robot. The key turner's three also have to resist the
key's turning torque — still to be measured with `print_key_fit_test.scad`.

**Prints affected:** dial front assembly (reprint), key-turner base, 10
retainers. SketchUp models rebuilt with the magnets (scene "Door side: rubber
magnets" in each).

## Key-turner v1 (2026-10-06): cap over the bow, Oldham-style, motor on the key axis

Replaces v0.1's thumbscrew clamp (sized before the key was measured).
`cad/key_turner_housing.scad`, inputs in the entry below.

- **Grip.** A cap (PETG-CF) slides over the key's flat head: slot 3.3mm
  (bow 2.5-2.9 + 0.4) x 30mm (bow 24.6 + 2.7 each side), mouth at 18.5mm from
  the door (beyond the steep taper, so it only ever touches the flat part),
  lead-in chamfer, slot bottom 0.6mm past the key tip. Its top has a tongue
  at 90deg to the slot that sits in a groove in the motor hub. So the cap is
  the middle disc of an Oldham coupling and the bow is one of its jaws: the
  unit can sit up to 2.7mm off the key axis in any direction and still turn
  the key with no side load on the lock — it is placed by hand and the key
  wobbles in the lock, so exact alignment can't be counted on. Axially the cap
  is trapped between the key tip and the hub (0.6 / 0.5mm).
- **Drive.** NEMA17 straight on the key axis (single motor, no gearing yet:
  the key's torque is unknown; 2:1 can be added later as in the dial unit).
  Hub on the D-shaft, 13.5mm of bore all on the shaft's flat; optional grub.
  Backlash ~3-4deg total (two sliding joints), fine for finding a stop at ~100deg.
- **Frame.** Base plate r43 with a 28mm opening that passes the bow as the unit
  slides on; 3 legs at r36 (180/60/-60deg, none toward the dials); motor plate
  on M6x20 countersunk self-tappers (the dial unit's bench-proven 5.4 pilot;
  **Correction 2026-10-06 evening:** M6x16, Paul's choice, see the top entry);
  motor on 4x M3x10 countersunk in the same 6.3mm countersinks as the dial sled.
- **Fit next to the dial unit.** The keyhole is 125.2mm from the dial plate's
  centre, level with it, so ~50mm from the dial plate's edge: the key turner
  reaches 43mm (base) / 29mm (motor plate) toward the dials. Toward the door's
  left edge (36.5mm away) the motor plate reaches 47mm, which is fine because
  the door sits flush with the safe body (Paul).
- **Door attachment: not decided** — to be chosen together with the dial
  unit's (Paul wants the same magnets in both). The base plate's door face is
  plain for now.
- **Checks.** STLs watertight, one body each. `cad/tools/key_turner_check.py`:
  key dummy (built from the caliper readings) + cap + hub + motor + frame at
  key angles 0/50/100deg and key offsets up to 2.5mm in five directions: no
  overlap (0.000mm^3). Sanity: a 2.0mm slot gives 166mm^3 of overlap, and a 4mm
  offset (past the 2.7mm range) 1.8mm^3, so the check sees real clashes.
- SketchUp review model: `cad/sketchup/key_turner_sketchup_build.py` ->
  `fichet_key_turner_v1_2026-10-06.skp` (4 scenes). Every part closed with outward
  faces; volumes within 1% of the STLs.
- **Not verified:** the key dummy's outline between the measured points
  (swelling width, the bow's exact outline) is approximate — hence the fit
  test print (`print_key_fit_test.scad`: cap + a hand lever with a hole 50mm
  from the axis for a luggage scale, which also measures the key's torque).

## 2026-10-06: key-turner inputs (Paul's measurements)

- Lock hole 12.05mm dia. Centre to centre (caliper far/near average): top-left
  dial hole 110.13mm (far 122.25 / near 98.01), bottom dial hole 126.95mm
  (far 139.4 / near 114.5). Check: far - near should equal the two hole
  diameters (25.0): bottom 24.9, top-left 24.24, so the top-left pair carries
  ~0.4mm of uncertainty. Solving both: the keyhole is at (-125.2, -1.8) in the
  dial unit's frame — 125.2mm from the dial plate's centre, level with it, so
  ~50mm from the 150mm dial plate's edge (the earlier ~55mm "gap" note was a
  photo estimate of something else).
- Key: 84.75mm long; fully inserted it protrudes 31.89mm from the door; turns
  clockwise ~100deg then stops; bow vertical at insertion. Calipers (with
  photos): bow 24.60 wide, 2.90 thick near the top; swelling 9.48 thick at
  ~8mm from the door; collar 7.97 dia to ~5.6mm; shaft 4.72; bow at full width
  from ~12.6mm; steep taper from the swelling over ~10mm, then 2.75 -> 2.5 over
  the last ~13.8mm; ring hole 10.75 with 6.6mm of metal to the bow's end. Door
  flat for 50mm around the lock, flush with the body; keyhole edge 30.45mm from
  the door's left edge.

## 2026-10-06: motor screws countersunk instead of counterbored

Paul printed the motor sled: the 2mm-deep flat counterbores for the motor
screws came out full of stray strings that were hard to dig out. Cause:
the sled prints inner face down, so each counterbore's flat shoulder is
printed in mid-air (an unsupported bridge ring around the 3.4mm hole). He
has M3 countersunk screws, so the 12 counterbores are now **90deg
countersinks**: a cone prints as a 45deg overhang, each 0.2mm layer
stepping in 0.2mm, with no bridge.

- Cone: **6.3mm mouth** on the inner face down to the 3.4mm clearance hole
  (1.45mm deep). Paul's screws are a generic kit (M3x10 ×55) that doesn't
  say which head standard, so the cone works for both: ISO 10642 M3 heads are
  dk 6.72 theoretical, k 1.86 ([Engineers Edge](https://engineersedge.com/hardware/bs_en_iso_10642_14583.htm));
  DIN 7991 M3 heads dk 6.0 max, k 1.7 max ([globalfastener DIN 7991](https://www.globalfastener.com/standards/detail.php?sid=NTUx)).
- Screw: **M3x10 countersunk** (length includes the head). Thread in the motor's
  4.5mm-min holes: ISO head (0.21mm proud) **3.79mm**, DIN head with its 0.2mm
  land **3.95mm**, DIN head without a land **4.15mm**. All three asserted in the
  SCAD (3.5 to 4.2). The first pass used a 7.0mm mouth: fine for ISO heads
  (4.14mm) but a DIN head could have gone 4.5mm deep and bottomed — caught
  before printing; the assert now fails on the 7.0 value. M3x8 would grip only
  ~2mm; M3x12 would bottom out.
- Side benefit: the old cap heads stood 1mm proud into the gear cavity;
  countersunk heads are within 0.21mm of the face (nothing moves within 4.5mm of it).
- Re-checked: layout check all pass (countersink to spring pocket 2.49mm
  over the 2mm requirement, was 2.60 with the 6.5mm counterbore);
  interference check no overlap (largest 0.083mm^3, the dummy screw heads
  touching their own seats — faceting); sled STL watertight, one body,
  90.76cm^3; slices through a screw hole show the cone 6.2 -> 4.9 -> 3.5mm at
  z = 0.05 / 0.7 / 1.4mm as designed; the SketchUp build script's sled
  updated the same way (closed, volume within 0.1% of the STL), and the
  SketchUp model rebuilt from it (`fichet_dial_unit_v2_geared_2026-10-06b.skp`)
  with a new scene 6 showing the sled's door-side face and its countersinks.
- Only the sled changes; the front plate, deck and drivetrain are untouched.

## v2 (2026-10-05): geared drivetrain on 608 bearings — the Oldham coupler could not have worked, and the hole pattern was wrong

**What prompted it.** Paul, with every printed part in hand: "the motor
spindles do not line up with the center of the holes for the dial turners
... see if there is an orientation for the motors where they can all be
mounted to the same sled and align with the holes. If not ... a flexible
coupler, but another option would be to add another level to the robot
and work on gearing ... I do have a stock of 608 bearings ... I want to
nail this on the first try."

### Findings

1. **No orientation exists.** Two NEMA17 cans (42.3mm square) can't have
   shafts closer than 42.3mm in any orientation (the narrowest a square
   gets is its side length). The two top door holes are 33.0mm apart. So
   at least one motor always has to sit off its dial; a coaxial direct
   drive would need the motors stacked at two or three depths (+50-100mm
   of overhang off the door, on magnets) — rejected.
2. **The v1 Oldham coupler could not have worked.** The disc's tongues
   were `slot_length - 1` long inside **closed** slots, so the disc could
   slide only +/-0.5mm, against the +/-6.9mm the 6.93mm offset needs — it
   would have jammed on the first turn. (`oldham_slot_length()` used the
   tongue *width* + 2x offset, which is the rule for a short square key,
   not a full-length tongue.) Separately, the real 24mm motor shaft
   reaches 18mm past the sled into a 20.8mm cavity: through the motor
   hub's 3.5mm bore, through the disc and into the dial hub. The modules
   are removed from `common_mounts.scad` (git history keeps them).
3. **`dshaft_bore()` cut an open slot, not a D.** Its "flat" was a cube
   added to the *cut* from 1.85mm off the axis out past the hub wall, so a
   12mm hub came out as an open "C" (checked with a cross-section render:
   one contour, no closed bore). Only the set screw's friction could have
   driven it. Rewritten as a real D (round bore intersected with the flat
   line at 2.15mm), D only over the flat's length. This also fixes
   `key_turner_housing.scad`'s gripper hub (STL re-rendered).
4. **The hole pattern was wrong.** The 36mm equilateral triangle was a by-
   eye photo read that was never confirmed. Re-measured from the door
   photos with software tick detection it came out isosceles, then Paul
   measured with calipers (far/near jaw readings, centre = average, which
   cancels the jaws sitting off the line of centres):

   | pair | far | near | centre |
   |---|---|---|---|
   | A-B (top, left-right) | 45.90 | 20.12 | **33.01** |
   | A-C, B-C (down to the bottom hole) | 55.0 | 30.0 | **42.50** |

   Holes 12.97 / 13.0mm dia. Depths from the door face: the star starts
   at 3.14mm; the caliper depth gauge (~2mm wide) stops at 8.92mm because
   the star's slots narrow toward a point; a real key goes in to 15.5mm.
   (A first write-up had 8.92 as the star's width at the mouth and 13.3 as
   the hole depth — a terminology mix-up, corrected with Paul the same
   day; what the 13.3 reading was is still to be confirmed.) The real
   key's blade read 0.91mm wide this time, but the printed turner at
   1.04mm is still loose in the socket, so the plug stays at 1.04 (Paul).
   The short side runs across the top; the other two meet pointing down to
   the bottom of the safe (Paul). v1's plate was up to ~5mm off. The two
   photo methods had disagreed by ~1mm (33.3/43.3 from the old angled
   photos, ~32.6/42.5 from the new square-on ones once corrected for the
   scales sitting a few mm above the door), which is why calipers were
   needed.

### Options considered

- **Fix the Oldham** (open slots or short tongues, longer motor hub):
  keeps the floating dial coupler, but a ~7mm-offset disc orbiting every
  turn in PETG-CF, ~2-3deg of backlash from two sliding joints, no torque
  gain, and three floppy couplers to line up with three sockets by hand.
- **Stagger the motors axially** for coaxial drive: long overhang (see 1).
- **Belts**: three belt planes plus tensioners — more parts than gears.
- **Gear stage on 608 bearings (Paul's suggestion) — chosen.** Each motor
  can sit anywhere on a circle around its dial, the dial shafts get real
  bearings, the reduction adds torque headroom (the dial torque is still
  unmeasured), and printed m1 gears have ~1deg of backlash.

### The design (`cad/dial_unit_housing.scad` v2)

- **Gear-shaft** (x3, PETG-CF, one piece): 8-tooth spline plug (same
  geometry as the test key) + 7.85mm journal + 1.5mm spacer + **28T module-1
  spur gear**, 6mm face. Runs in **two stacked 608 bearings** in a 16mm boss
  on the front plate; a 2mm lip on the door side holds the outer ring (lip
  hole 19.5mm, between the shield edge D2 19.2 and the abutment limit Da
  20); the spacer (11mm) bears only on the inner ring (SKF 608-2Z abutment
  da 10-12mm).
- **Spring-loaded plug.** The journal is a sliding fit, so the whole
  gear-shaft slides 7mm. A light compression spring between the gear's
  rear face and the sled pushes it forward against the rear bearing.
  Mounting: put the unit on the door; any plug that doesn't line up with
  its star is pushed back and the plate still seats flush; then turn each
  motor slowly and its plug snaps in. Plug tip at the forward stop is 7mm
  below the plate face = 3.9mm into the star (the star starts 3.14 below
  the door face) — the same depth the hand test key reached. The plug is
  5mm long, the length of the real key's straight-sided section; deeper,
  the socket's slots narrow (shape unmeasured), so it is not lengthened.
- **Pinion** (x3, PETG-CF): **14T module-1**, 14mm face (6mm gear + 7mm
  travel + 1) so the gear never leaves it. **2:1 reduction**: 400 full
  steps per dial turn, 20 per dial position. Profile shift +0.2 pinion /
  -0.2 gear (a 14T pinion undercuts below ~17T; the shifts cancel, so the
  centre distance stays 21mm). Its D-bore is round for the first 2.5mm and
  D only where the shaft's flat is, so the end of the flat locates it
  axially; it is also trapped between the sled and the boss tops, so the
  set screw is optional (grub screw only — a cap screw's head would hit
  the gear).
- **Motors** on a 21mm circle around their dials, directions and rotations
  from an annealing search over every clearance (below). The cans overlap
  the dials only in plan view — they sit behind the sled, the gears in
  front of it.
- **Front-to-sled joint**: 3 legs + M6 countersunk self-tap (bench-proven
  in v1), keyed (asymmetric). **Deck**: 3 legs between the cans, Mega base
  plate re-placed (244deg, offset (-2.5,-5)) so its screws clear the deck
  countersinks by >21mm.
- Stack: door 0 | plate 0-5 | bosses to 16 | gear 17.5-23.5 (24.5-30.5
  pushed back) | pinion 17-31 + hub to 35 | sled 35.5-41.5 | cans to 89.5 |
  deck 95.5-100.5. Motor shaft tip lands 0.5mm inside the pinion. Motor
  screws: M3x10 countersunk, flush in 90deg countersinks, 4.1mm of thread in
  the motor's 4.5mm holes (was M3x8 in 2mm counterbores — see 2026-10-06
  entry above).
- **Pointer** now points up on the door for real (the top pair side).
- Magnet field: 147 pockets, kept clear of the bearing pockets.

### Verification (all re-run with the caliper numbers)

- `cad/tools/dial_layout_check.py` (reads every position from the SCAD's
  own echo output): all 2D clearances pass with >= 1.4mm left over the
  stated requirements (can-to-can >= 6mm, pinion vs the other dials' gears
  >= 3mm, top gear tips 3.4mm apart, countersink + 3mm driver access clear
  of every can, legs clear of gears/pinions/screw heads, everything inside
  the 150mm plate); gear mesh from the SCAD's own tooth outlines: zero
  overlap through a full tooth pitch at zero backlash (conjugate), 0.12mm
  flank gap as printed, still no overlap with the centre distance 0.15mm
  short; contact ratio 1.52; axial stack and pinion float rows all pass.
  What-if: the layout passes with any one hole distance +/-1mm.
- `cad/tools/dial_interference_check.py`: every part rendered in place
  (plus dummy cans, bearings and M3 heads), 36 static pairs + 114 moving
  pairs at 12 poses (gear phase x 4, spring travel 0/3.5/7mm): **no
  overlap** (largest 0.000mm^3). Sanity check: deliberately mis-phasing a
  gear half a tooth gives 20mm^3, so the check does detect real overlaps.
- trimesh: every STL watertight, one body per part.
- SketchUp review model (`fichet_dial_unit_v2_geared.skp`) built from the
  same numbers; per-part volumes match the SCAD STLs within 1%.

### Not verified yet — what the first prints have to confirm

- **2026-10-05: door-pattern test PASSED** (Paul): the plate fits the door perfectly and all three dial turners turn easily. The caliper hole pattern is confirmed on the real door.

- **Door-pattern test first** (`print_dial_pattern_test.scad`): bearing
  press fit (22.15mm pocket), the journal sliding in the bearings (7.85mm),
  and all three plugs seating together on the real door. Three rigid shafts
  into three sockets is over-constrained, and each plug can only float a
  few tenths of a mm sideways (0.35mm diametral clearance at the plug
  tips, 0.15mm journal-to-bearing), so this is the check. (An earlier
  version of this note counted on a wide star mouth for extra room — that
  came from the mislabelled 8.92 reading and was wrong.)
- Springs: none on the BOM yet (<= 8mm OD, ~18-20mm free, solid < 10mm).
- Gear teeth and plug teeth are printed plastic: run the dial motors at
  ~1A (TMC2209) until the dial torque is measured — 2:1 doubles what the
  motor can put into the plug.
- Paul measured the key's blade width at 0.91mm this time (earlier
  1.04-1.06); the plug keeps the bench-tuned 1.04, which clicked the dials.
- Motor cable exits: rotate each can in 90deg steps at assembly so its
  cable side faces a free gap.

## Electronics sled switched to the Mega base-plate mount (2026-10-04): bench results on the coupon and the motor sled

Bench results from Paul, same day as the fourth round below:
- **Motor sled fit is good** (the latest motor sled, with the
  `motor_pad_r` outline and the keyed countersunk joint pattern).
- **Mega base plate vs `cad/mega_base_fit_test.scad`**: the real base
  plate "fits on the screws as placed", but only 3 of the 4 screws would
  go in. Paul's call: 3 is enough to hold it. Which hole binds wasn't
  reported, so the 4 positions are unchanged (a ~0.4mm error against a
  3.1mm hole was the known risk, see the entry below); it just means one
  hole is a spare.

Change: `electronics_deck()` now mounts the Mega only through its base
plate. The 4 standoff posts and the `mega_base_mount` switch are removed;
the 4 M3 self-tap pilot holes (2.6mm, through the deck) at
`mega_base_hole_pts` are always present. `mega_hole_pts` (the board's own
PCB holes) stays only to size the deck outline, and `mega_rotation = 30`
stays because the coupon was fit-checked at that orientation. The deck
outline is unchanged from the previous round's base-plate mode (still
reaching the two end-flange holes). Re-rendered clean; trimesh: 12
watertight bodies; deck now has exactly 4 x 2.6mm pilot holes plus the 3
M6 countersunk holes and no posts. Build order note updated: bolt the deck
to the legs before screwing the base plate on (2 of the 3 M6 screws sit
under the base plate; their heads are flush, so it lies flat over them).

Still open: the pointer direction on the real door, the 2mm magnet wall
(`magnet_wall`), and the first front-leg M6 self-tap (thread it in by
hand). Paul's next step is a full dialer-assembly fit with the new base
plate and sled.

## Fourth round (2026-10-04): countersunk keyed joint, pointer tab, magnet field, and a Mega base-plate mount

Paul's feedback after the previous round was merged (PR #6):

1. Use countersunk screws for the base-plate-to-motor-sled mount "to
   ensure accurate alignment every time", make the sled fit so "the
   same motor is always aligned with the same dialer", and add a key or
   arrow on the base plate so the dialer assembly can always be oriented
   the same way on the safe door.
2. Check for a drawing of the plastic base that ships with the Arduino
   Mega 2560, and try an electronics sled with no standoffs: the base
   plate screwed to the sled with M3 self-tap screws.
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

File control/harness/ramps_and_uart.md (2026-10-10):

# RAMPS board + UART pigtail — what goes where

> **Revision 2026-10-09.1** · all four drivers on the RAMPS (key in E0); UART pigtail replaces the hub board · log: `docs/revisions.md`

A single bench sheet pulling together everything that gets fitted to the
RAMPS, plus the UART pigtail, so nothing is missed. It restates
`control/wiring.md` (the reference — read it for the *why* and the sources)
and the manual's §2.4, §2.5 and §2.7. The pigtail is drawn in
`control/harness/uart_pigtail.svg`. (Until revision 2026-10-08.2 this sheet
was `ramps_and_hub.md`.)

Dial naming: **A = top-left, B = top-right, C = bottom**, standing in front of
the safe.

**Board map.** The Fasizi board's own silkscreen is sparse; this drawing of
the same layout labels every header. Directions in this sheet are with the
power screw terminals on the left, as drawn.

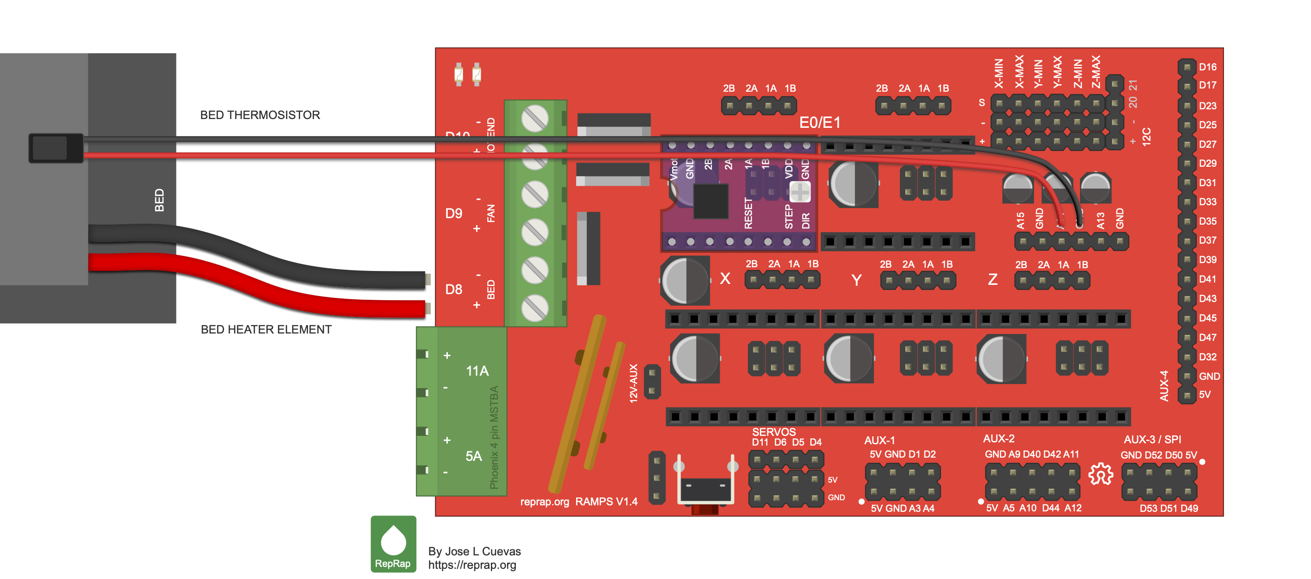
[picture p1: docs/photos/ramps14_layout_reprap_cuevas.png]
RAMPS 1.4 layout


*RAMPS 1.4 layout, matching Paul's Fasizi board. Illustration by José L.
Cuevas, [RepRap wiki, File:Rampsv14_wiring_bed.png](https://reprap.org/wiki/File:Rampsv14_wiring_bed.png),
used under the [GNU Free Documentation License](https://www.gnu.org/licenses/fdl-1.3.html)
(the wiki's licence for its content). The bed heater and thermistor wiring
drawn in it are not used by this robot.*

**Revision 2026-10-08.1:** the key driver is on the RAMPS now (E0 socket), so
all four drivers are here. There is no remote driver board and no inter-unit
signal cable; the key motor's own cable plugs into the E0 motor header.

**Revision 2026-10-08.2:** the hub board is replaced by the **UART pigtail**,
a six-lead harness with R1 in the TX2 lead and one solder splice (B).

---

## A. On the RAMPS board

### A1. Jumpers under the driver sockets (set the UART address)

Fit these **before** pressing the RAMPS onto the Mega and before plugging the
drivers in.

| Socket | Driver | MS1 | MS2 | MS3 | Address |
|---|---|---|---|---|---|
| X | dial A | — | — | — | 0 |
| Y | dial B | **jumper** | — | — | 1 |
| Z | dial C | — | **jumper** | — | 2 |
| **E0** | **key** | **jumper** | **jumper** | — | **3** |
| E1 | (empty) | — | — | — | — |

- **Never fit an MS3 jumper on any socket.** On the BTT V1.3 the MS3 position
  is the UART line; a jumper there ties UART to 5 V and kills the bus.

### A2. Drivers

- **Four** TMC2209: dial A in **X**, dial B in **Y**, dial C in **Z**, the
  **key in E0**. **Orientation:** the driver's motor-side row (VS, GND, A2,
  A1, B1, B2, VIO, GND) goes in the socket row **nearer that axis's 4-pin
  motor header**; EN … DIR in the other row. Check each socket with the
  multimeter first (manual §2.4 step 1). A reversed driver is destroyed.
- Each of the four has its two EN-end pins **cut flush underneath** (manual
  §2.3). No soldering: the DIAG and UART leads clip onto pins on top.
- Heatsink on each. **VREF pot to minimum** on every driver first.
- **E0 is the top-left socket** (nearer the power terminals), with its
  motor header (2B 2A 1A 1B) at the top edge above it, labelled "E0/E1"
  with E1's. **E1 is the top-right socket: leave it empty.** (KiCad: E0
  socket U5 at the left of the top row, E1 socket U6 to its right; each
  motor header sits above its own socket.) Don't bridge R10 on any driver.
- X, Y, Z are the bottom row, left to right, each with its motor header
  above it.
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

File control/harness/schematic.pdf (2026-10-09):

# Overview

What connects to what. Each block is drawn in full on the sheet named in it.

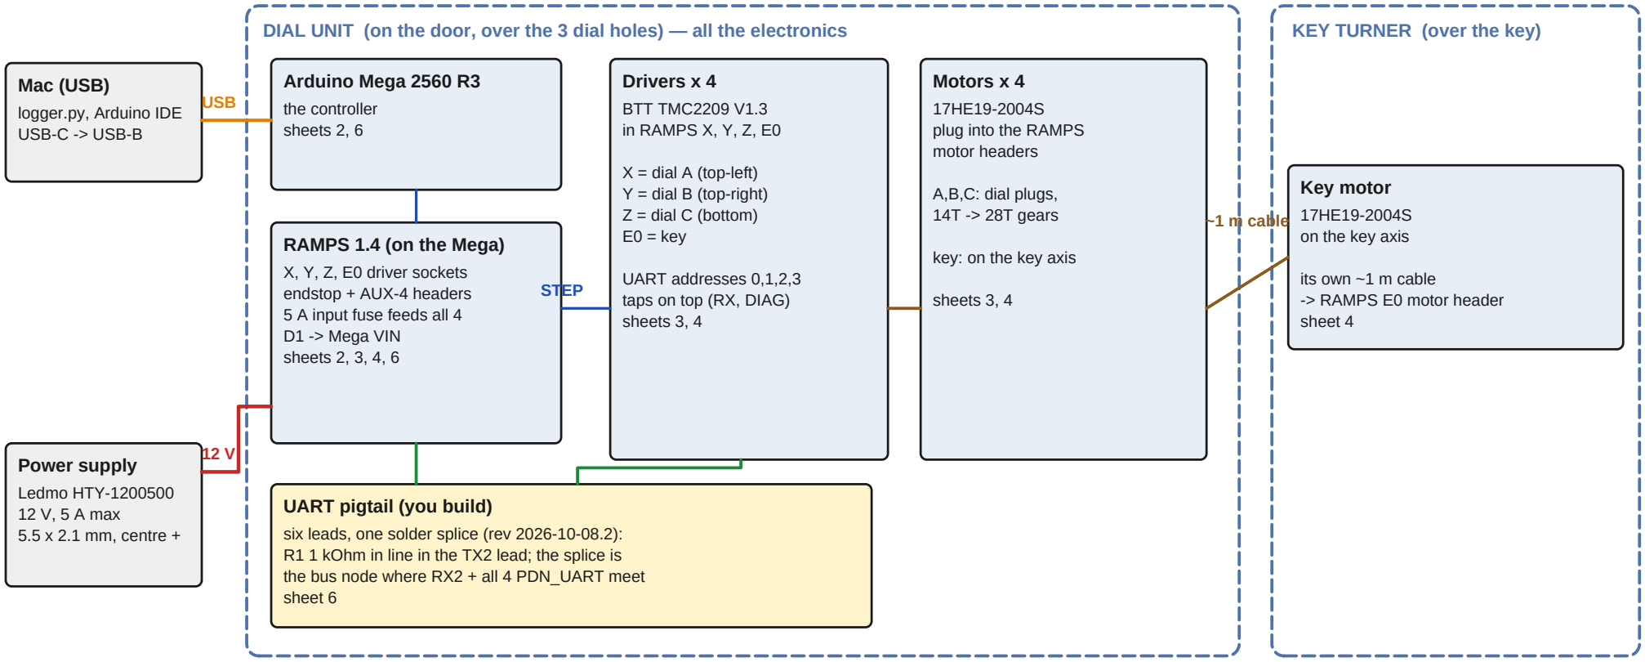
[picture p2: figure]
Mac (USB); logger.py, Arduino IDE USB-C -> USB-B; Power supply; Ledmo HTY-1200500 12 V, 5 A max 5.5 x 2.1 mm, centre +; Arduino Mega 2560 R3; the controller sheets 2, 6; RAMPS 1.4 (on the Mega); X, Y, Z, E0 driver sockets endstop + AUX-4 headers 5 A input fuse feeds all 4 D1 -> Mega VIN sheets 2, 3, 4, 6; Drivers x 4; BTT TMC2209 V1.3 in RAMPS X, Y, Z, E0; X = dial A (top-left) Y = dial B (top-right) Z = dial C (bottom) E0 = key; UART addresses 0,1,2,3 taps on top (RX, DIAG) sheets 3, 4; Motors x 4; 17HE19-2004S plug into the RAMPS motor headers; A,B,C: dial plugs, 14T -> 28T gears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

Fichet safe robot — wiring schematic | Sheet 1 of 7

Overview

2026-10-08 · revision 2026-10-09.1 · from control/wiring.md

+12 V | +5 V (logic, VIO) | GND | UART bus
STEP / DIR / EN, button | DIAG (stall) | motor coils | jumper / tie / spare
bought module | board you build | already on the RAMPS / Mega: nothing to buy
DIAL UNIT (on the door, over the 3 dial holes) — all the electronics | KEY TURNER (over the key)
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

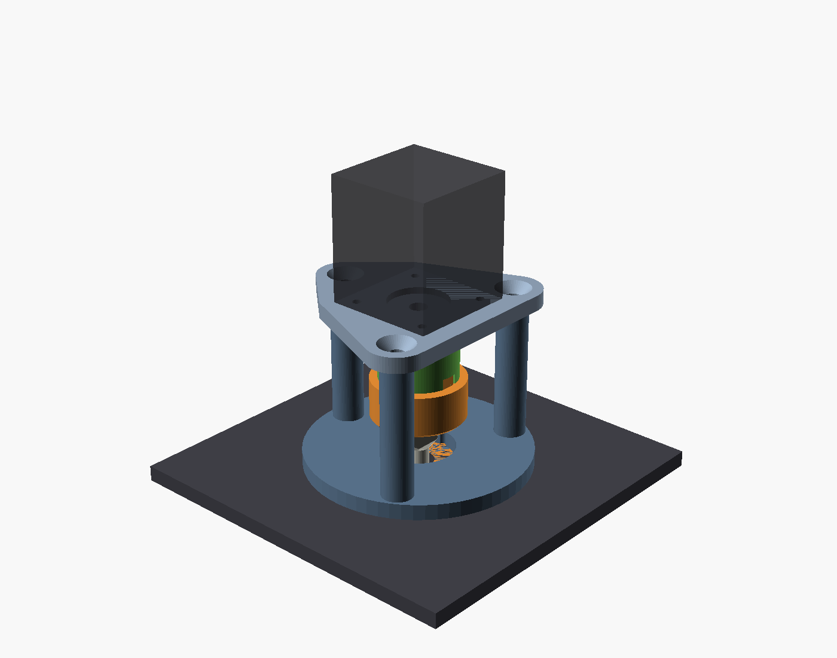
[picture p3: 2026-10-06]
cad/renders/key_turner_v1_overview.png

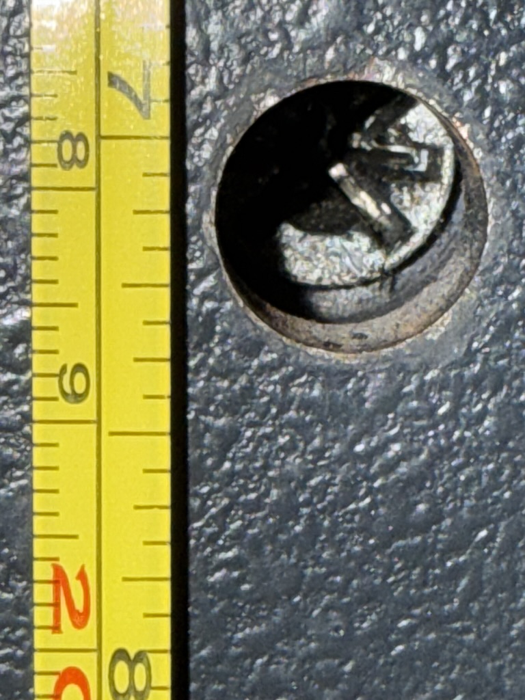
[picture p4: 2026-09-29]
docs/photos/dial-holes-tape-overview.jpg

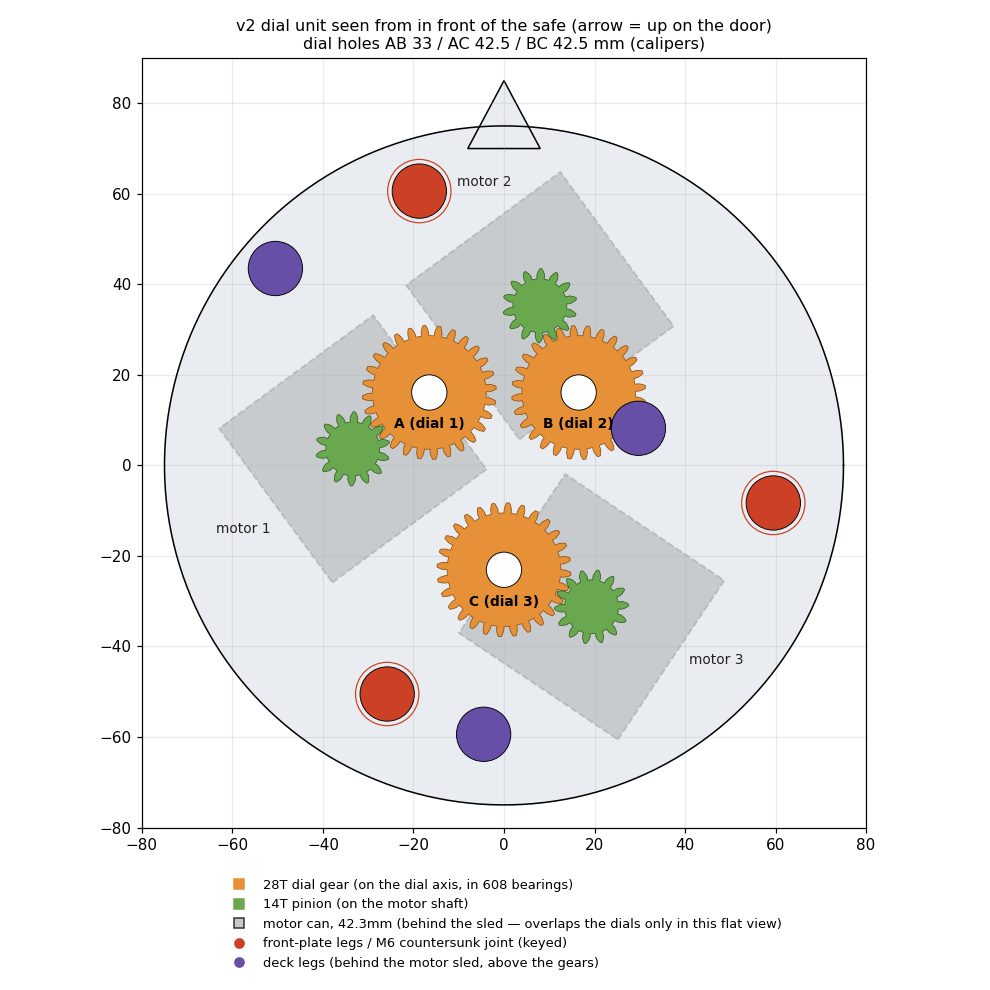
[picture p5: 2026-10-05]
cad/renders/dial_unit_v2_door_view.png

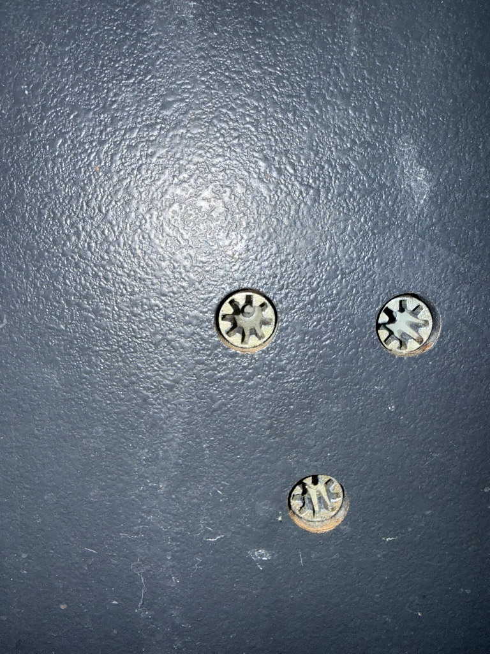
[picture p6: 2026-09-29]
docs/photos/dial-holes-closeup.jpg

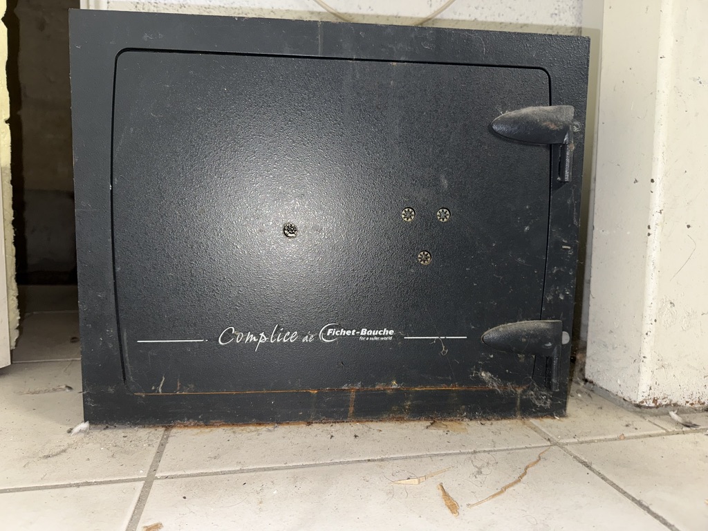
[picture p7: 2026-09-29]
docs/photos/door-overall.jpg

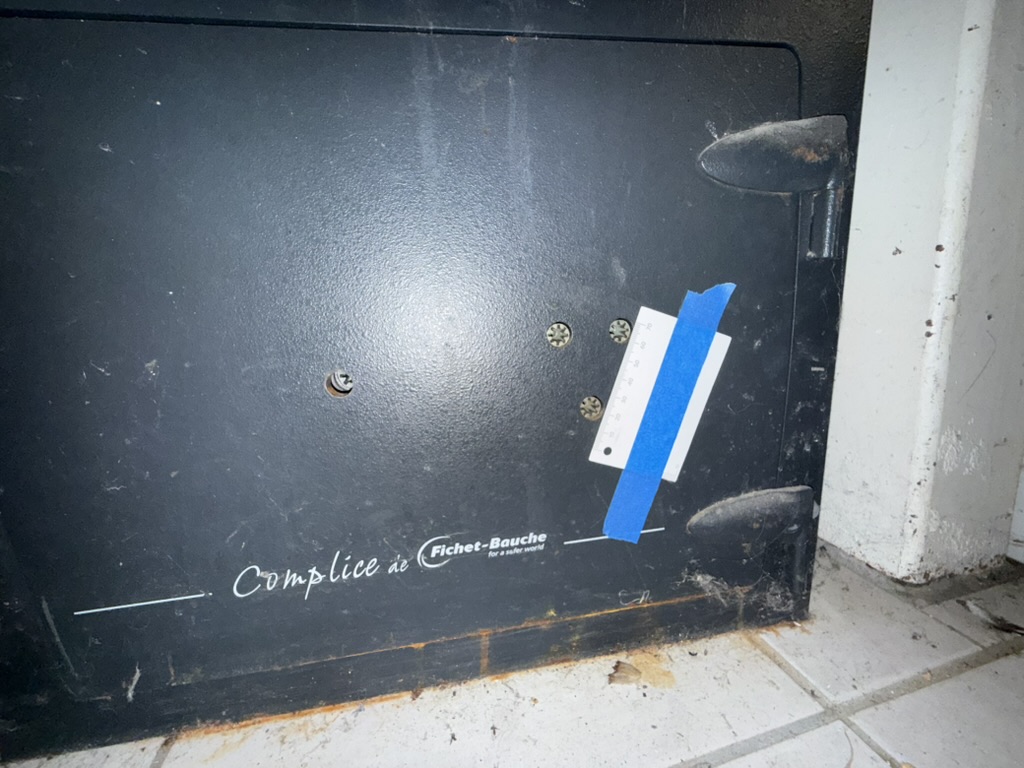
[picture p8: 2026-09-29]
docs/photos/dial-holes-ruler-4.jpg

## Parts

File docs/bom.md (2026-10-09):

# Bill of materials

> **Revision 2026-10-09.1** · key driver on the RAMPS E0 socket; UART pigtail replaces the hub board · log: `docs/revisions.md`

**Revision 2026-10-08.1 (2026-10-08):** the key driver moved to the RAMPS
**E0** socket. Several parts that were ordered are **no longer used** (keep
them as spares): the 1.1 A PTC fuse and the 1.6 A glass fuse kit + its printed
holder (no separate key-branch fuse), the two 100 µF capacitors (no remote
board), the 6-conductor QUARKZMAN cable and the Phoenix 8-pin connectors (no
inter-unit signal cable), and the female header strips (no driver socket on a
perfboard). The order records below are kept as history.

**Revision 2026-10-08.2 (2026-10-08):** the hub board is replaced by the UART
pigtail (`control/wiring.md` §5), so its perfboard and male header pins are
no longer used either. What is still fitted: R1 (1 kΩ) in the pigtail's TX2
lead, F–F jumpers (pigtail leads, DIAG leads), heat shrink, a zip tie, the
DC-jack adapter + 20 AWG wire (PSU → RAMPS "5A"), the start/stop button, and
the key motor's own cable into E0.

What to buy, based on decisions locked in so far (two-unit architecture,
StallGuard force feedback on all 4 motors — see `control/sequence.md` and
`docs/decisions.md`). Prices are rough EUR estimates for common hobbyist
parts (Amazon.fr / AliExpress / RobotShop-class pricing as of late 2026) —
**verify at purchase time**, they weren't pulled from a live listing.

Quantities assume the confirmed layout: 3 dial motors + 1 key-turner motor
= 4 motors total, 4 drivers total (all four on the RAMPS since revision
2026-10-08.1 — see the
driver-placement rationale in `control/sequence.md`).

## Order status (as of 2026-09-29)

Four orders placed 2026-09-29, checked against every line below:

| # | Vendor | Total (incl. VAT) | Contents |
|---|---|---|---|
| 1 | Amazon.fr | €46.81 | PCB/perfboard kit, AS5600 encoder ×4, 12V/5A power supply, heat shrink tube assortment |
| 2 | Amazon.fr | €286.52 | TMC2209 drivers ×5, shielded 6-conductor cable (18 ft), RAMPS 1.4 shield, Arduino Mega 2560, M–M jumper wires ×2 kits, 1kΩ resistors ×100, heat gun, soldering station, NEMA17 motors ×5, USB-C→B cable, momentary pushbuttons ×12 |
| 3 | Amazon.fr | €13.99 | Phoenix 5.08mm 8-pin screw-terminal connectors (substituted for the JST-XH spec below) |
| 4 | Bambu Lab | €428.42 (order also includes general printer supplies not on this BOM) | PETG-CF filament (1kg), tungsten carbide hotend — plus PETG Basic ×2, PLA Basic ×2, and a Bambu Lab AMS 2 Pro, none of which are BOM items |

Status is marked inline in each table below: ✅ ordered, ⬜ still to buy.

**Still to buy:**
- **Multimeter** — on the prototyping-basics checklist, not in any order. **Update 2026-10-07 (Paul): he already has one. Nothing to buy.**
- **F–F / M–F jumper wires** — both jumper-wire items ordered are M–M only; the RAMPS DIAG-to-endstop-header wiring and other point-to-point hookups will likely need female-ended jumpers too. **Update 2026-10-07:** the harness as designed (`control/wiring.md` §10) uses **F–F only, ~20 × 10–20 cm**; M–F aren't needed for it. **Ordered 2026-10-07** (amazon.fr, Paul).
- **Solder wire** (consumable) — unconfirmed whether it's bundled with the Yofuly soldering station kit; check contents on arrival and buy separately if not included. **Update 2026-10-07 (Paul): the station came with solder and solder wick. Nothing to buy.**
- **Harness parts (added 2026-10-06, `control/wiring.md` §10):** 2.54mm female and male header strips (**on hand** from another order, Paul 2026-10-07), a ~1.1A-hold radial PTC fuse (×2), 100µF ≥25V electrolytic (×2), a female **5.5×2.1mm** DC-jack-to-screw-terminal adapter (the PSU is a Ledmo HTY-1200500, 5.5×2.1 barrel, centre positive — Paul, 2026-10-06), ~1m each of red/black 20AWG wire, flush cutters if not already owned (**Paul has them**, 2026-10-07). Use the multimeter (on hand) before connecting the remote driver board. **Ordered from amazon.fr, 2026-10-07 (Paul)**: PTC fuses, capacitors, F–F jumpers, DC-jack adapter, wire, zip ties. None of the PTC listings arrives soon, so hub F1 is a **1.6 A glass cartridge fuse in a printed holder** until it does (`control/wiring.md` log 2026-10-07). **Every discrete part, one line each: see the next section.**

## Electronics assembly — every discrete part (2026-10-07)

**Why this section:** Paul noticed fuses, capacitors, resistors and diodes
on the schematic (`control/harness/schematic.pdf`) that weren't in the
early BOM. **Most of them are already soldered on the RAMPS or the driver
modules** (table B): nothing to buy. The parts you buy and solder
yourself are in table A. **🛒 = still to buy.**

Status: 🛒 **TO BUY** · ✅ ordered or on hand · ⚪ already on a board you
bought (nothing to buy).

**Where to buy the 🛒 items:** `docs/order_remaining_parts.md` (2026-10-07)
has specific picks for amazon.fr and mouser.fr, with prices and stock, and
lists what neither site has. amazon.fr covers everything in one order.
**Ordered 2026-10-07** (amazon.fr, Paul): every item that was 🛒 below.

**A. Parts you buy and fit** (the wiring; the UART pigtail since revision
2026-10-08.2 — the hub perfboard and male header rows are spares now). **Revision
2026-10-08.1:** the "remote board" rows (fuse, PTC, C1, female headers,
Phoenix J1/J3, 6-conductor cable, remote perfboard, standoffs) are **no longer
used** — the key driver is in the RAMPS E0 socket. They stay in the table as a
record of what was bought; treat them as spares.

| Status | Ref | Part | Spec | Qty (+ spare) | Where it goes | Source |
|---|---|---|---|---|---|---|
| ✅ ordered (amazon.fr, 2026-10-07); arrives late | **hub F1** | **Resettable fuse (PTC), radial** | **~1.1 A hold, ≥ 16 V** (Bourns MF-R110 class) | **1 (+1)** | hub board: 12 V to the key-turner branch only | `control/wiring.md` §3.5, §5, §10 |
| ✅ ordered (Paul, 2026-10-07): AUKENIEN 120-pc slow-blow kit, **T, 5 × 20 mm, 250 V**, 12 values 0.5–10 A × 10 each (1.6 A among them), €15.99, Prime next day | **hub F1, for now** | **Glass cartridge fuse** | **1.6 A T (slow-blow), 5 × 20 mm** | 1 (+ 9 spare) | in F1's place until the PTC arrives. No clips or holder ordered: Paul prints a holder | `control/wiring.md` log 2026-10-07 |
| hardware on hand (check washers) | **hub F1 holder** | **Printed 5 × 20 mm fuse holder** (`cad/fuse_holder.stl`) | 2× M3 heat-set inserts, 2× M3x6 socket screws, **2× M3 washers (7mm OD)**, 1 QUARKZMAN spring (dial-unit spare) | 1 | beside the hub board or inline in the 12 V+ wire | `docs/housing_decisions.md`, 2026-10-07 |
| ✅ ordered (amazon.fr, 2026-10-07): Innfeeltech 100 µF 35 V radial, 50 pcs, €7.49, delivery Friday 9 Oct. **Not sold as low ESR** (the listing doesn't say) | **C1** | **Electrolytic capacitor** | **100 µF, ≥ 25 V** (35 V fine), low ESR | **1 (+1)** | remote board: across VM–GND, right at the key driver. The one ordered isn't sold as low ESR: see `control/wiring.md` log 2026-10-07 | §3.5, §6.1, §10 |
| ✅ on hand (another order, Paul 2026-10-07) | — | 2.54 mm male header strip (cuttable) | — | **1 strip** | *not used from revision 2026-10-08.2 (spare).* Was the hub's jumper pins and the remote board's J2 | §5, §6.1, §10 |
| ✅ on hand (another order, Paul 2026-10-07) | — | 2.54 mm female header strip (cuttable) | — | **1 strip** | remote: 2 × (1 × 8) + 1 × (1 × 2), the key driver's socket | §6.1, §10 |
| ✅ ordered (amazon.fr, 2026-10-07) | — | **F–F Dupont jumpers** | 10–20 cm | **~20** | 6 for the UART pigtail (one end cut off each; revision 2026-10-08.2); 4 plain ones from the drivers' DIAG pins to the endstop S pins (no DIAG soldering since 2026-10-08.2) | §2, §3.3, §5, §10 |
| ✅ ordered (amazon.fr, 2026-10-07) | — | **DC jack → screw-terminal adapter** | female **5.5 × 2.1 mm** | **1** | PSU → RAMPS '5A' terminal (revision 2026-10-08.1; was hub 12V IN). **Why:** the PSU ends in a barrel *plug*, and the RAMPS '5A' input is a screw terminal. This is the socket the plug goes into. The alternative is to cut the plug off and screw in the bare leads (find + with the multimeter): free, but it can't be undone. Not the Mega's own jack: that feeds only VIN, and the RAMPS motor rail would get no 12 V (D1 conducts only from that rail to VIN) | §5, §10 |
| ✅ ordered (amazon.fr, 2026-10-07) | — | **Hook-up wire** | **20 AWG, red + black**, ~1 m each | **1 + 1** | PSU adapter → RAMPS '5A' input (the hub's 12 V split went in revision 2026-10-08.1) | §5, §10 |
| ✅ ordered (amazon.fr, 2026-10-07) | — | **Small zip ties** | — | **~6** | cable strain relief, within ~20 mm of each plug | §4 |
| ✅ ordered (×100) | R1 | Resistor | 1 kΩ | 1 | in line in the UART pigtail's TX2 lead (revision 2026-10-08.2; was on the hub). The only resistor you fit | §3.2 |
| ✅ ordered (×12) | S1 | Momentary push button | 7 mm | 1 | start / stop, on the RAMPS Y_MIN S and − pins; mounts from under the deck (hole + recess, rev 2026-10-09.1) with its own washer and nut | §1 |
| ✅ on hand: **5 headers + 5 plugs** (Paul, 2026-10-07) | J3, J1 | Phoenix-style pluggable screw terminal | 5.08 mm, 8-pin, header + plug | 2 headers + 2 plugs (3 + 3 spare) | J3 on the hub, J1 on the remote board | §4 |
| ✅ ordered | — | Shielded cable | QUARKZMAN 22 AWG, 6 cores | ~300 mm | dial unit ↔ key turner | §4 |
| ✅ on hand | — | Perfboard (from the kit) | — | 2 pieces | *not used from revision 2026-10-08.2 (spares).* Were the hub and the remote board | §5, §6.2 |
| ✅ ordered | — | Heat shrink | — | — | over R1 and the UART pigtail's splice (the shielded cable it was also for is retired) | §4 |
| ⬜ not needed (revision 2026-10-08.1) | — | Standoffs | 4 mm | 4 | *not needed:* were for under the remote board, which is gone | §6.2 |

Tools: **nothing left to buy**. Paul has a multimeter, solder (with wick)
and flush cutters (2026-10-07). The harness uses **F–F jumpers only**. The M–F ones in the
"Still to buy" list aren't needed for it.

**B. Parts on the schematic that are already on a bought board: nothing to buy**

| Status | Ref | Part | Where | Source |
|---|---|---|---|---|
| ⚪ on the RAMPS | F1 (RAMPS) | MF-R500 resettable fuse, 5 A | '5A' input → +12 V rail (**all four drivers** incl. E0, + Mega VIN — revision 2026-10-08.1) | RAMPS 1.4 KiCad netlist (`control/wiring.md` log 2026-10-07) |
| ⚪ on the RAMPS | F2 | MF-R1100 resettable fuse (11 A) | '11A' heated-bed input: not used | same |
| ⚪ on the RAMPS | D1 | 1N4004 diode | +12 V rail → Mega VIN | same |
| ⚪ on the RAMPS | C3, C4, C6, C7, C9, C10 | 100 µF electrolytics | +12 V rail, by the driver sockets | same |
| ⚪ on the RAMPS | R18, R19, R20 (R16, R17) | 10 kΩ pull-ups | EN of the driver sockets (X, Y, Z, **E0**; E1 spare) to 5 V — keeps every driver off until the firmware enables it | same |
| ⚪ on each TMC2209 V1.3 | module's R3, R5 · R4 · C1, C2 · R10 | 0.11 Ω sense resistors · 20 kΩ CLK pull-down · 2 × 10 µF · R10 **not fitted** | the driver module itself | BTT V1.3 schematic (`control/wiring.md` §2, §3.5, §7) |
| ⚪ on the Mega | — | LED 'L' (D13), 5 V regulator, USB interface | the Mega itself | Arduino Mega 2560 R3 |

The 10 kΩ, the diode and the fuses drawn in grey on schematic sheets 2–4
are these parts: shown so the circuit can be followed, not to be bought.

**Substitution to be aware of:** the JST-XH 8-pin connector pair specified below was replaced with a Phoenix-style 5.08mm screw-terminal 8-pin connector (Order 3). Still detachable and keyed for the same purpose (unplugging the key-turner unit), just a different connector family than originally planned — flagging in case it wasn't deliberate, otherwise no action needed.

**Housing design note (2026-10-05, dial unit v2):** the printed Oldham coupler is gone (it could not have worked — see `docs/housing_decisions.md`, v2 entry). Each dial is now driven through a 14T/28T printed gear pair, with the dial shaft in two 608 bearings — see the "Dial unit v2" table below for what that needs.

## Core electronics — locked in

| Item | Qty | Est. unit price | Est. total | Status | Notes |
|---|---|---|---|---|---|
| NEMA17 stepper motor — **STEPPERONLINE 55Ncm 2A, pack of 5** | 1 pack (5, one spare) | €55.42 | €55.42 | ✅ Ordered (Order 2, €55.42) | 3 for dial wheels, 1 for key-turner, 1 spare. Checked live on Amazon.fr 2026-09-29: 55Ncm/2A is essentially the same torque class as the ~59Ncm hedge target (headroom against the still-open torque/effort unknown, see below), and STEPPERONLINE is a genuinely reputable brand here — 661 ratings at 4.7★, #1 best seller in category. The 5-pack is also cheaper than buying 4 singles (€55.42 vs. ~€84.52), with the 5th motor as a spare rather than waste. Note from the listing: on some units the 2 middle motor wires are swapped from the expected color coding — easy fix (lift the connector's white pins and swap), just don't mistake it for a wiring fault elsewhere. |
| TMC2209 stepper driver module (StallGuard, UART) — **BigTreeTech TMC2209 V1.3, 5-pack w/ heatsinks** | 1 pack (5, one spare) | €35.99 | €35.99 | ✅ Ordered (Order 2, €35.99) | Checked live on Amazon.fr 2026-09-29, settled on this after ruling out two others: a no-name GERUI 2-pack whose reviews show a real failure pattern ("1 of 2 doesn't work," repeated across several countries), and a listing badged "TMC2209" whose actual product-variant names ("R3-V3-4988") and description described A4988 hardware instead — a mislabeled/wrong-part risk, not just a lesser board. BigTreeTech is an established brand in this exact space (makes the SKR/Octopus boards much of the 3D-printer Klipper/Marlin community runs) and this listing had 491 ratings at 4.5★, a real sample size. The 5-pack also solves the quantity problem in one order (4 needed + 1 spare) rather than splitting across sellers, and includes heatsinks. |
| Arduino Mega 2560 (or genuine-compatible clone) | 1 | €15–40 | €15–40 | ✅ Ordered (Order 2, genuine Arduino Mega 2560 REV3, €49.19) | Chosen over an Uno/Nano for having enough hardware UART capacity for this design. (Correction from the earlier "4 dedicated UARTs" reasoning: `Serial` is tied up by USB, and all 4 drivers now share one UART bus on `Serial2` via TMC2209's built-in multi-drop addressing — see `control/sequence.md`'s new wiring-plan section. The Mega is still the right pick, just for a slightly different reason.) A genuine board is pricier but avoids clone USB-chip driver headaches — went genuine, hence €49.19 vs. the €15–40 estimate. |
| RAMPS 1.4 shield (for the Mega 2560) | 1 | €9–17 | €9–17 | ✅ Ordered (Order 2, Fasizi RAMPS 1.4, €10.99) | Plugs directly onto the Mega; 5 StepStick-footprint sockets, same physical pinout as the BigTreeTech TMC2209 boards above — no soldering for the 3 local dial drivers, they plug straight in. Only 3 of its 5 sockets get used (X/Y/Z); the 4th driver (key-turner) is wired off-shield per the driver-placement rule. Well-established part, e.g. ARCELI (4.2★, 255 ratings, €9.99) or DollaTek (4.2★, 124 ratings, €8.99). |
| 1kΩ resistors | ~10 (need 4) | €2–4 for an assorted kit | €2–4 | ✅ Ordered (Order 2, Innfeeltech 1K ohm ×100, €6.99) | ~~One per TMC2209, between the Mega's UART TX pin and that driver's PDN_UART pin.~~ **Correction (2026-10-06):** only **one** is needed for the shared bus — TX2 → 1kΩ → bus, RX2 and all four PDN_UART pins on the bus (TMC2209 datasheet Fig. 4.1; see `control/wiring.md` §3.2). Ordered a 100-pack of the exact value rather than an assorted kit — covers this need plus plenty of spares. |

## Power

| Item | Qty | Est. unit price | Est. total | Status | Notes |
|---|---|---|---|---|---|
| 12V DC power supply, 5A | 1 | €12–18 | €12–18 | ✅ Ordered (Order 1, ledmo 12V/5A-6A, €14.98) — on hand: **Ledmo HTY-1200500**, 5.5×2.1mm barrel, centre positive (Paul, 2026-10-06) | Sized up from an earlier 3A estimate to match the higher-torque (2A/phase) motors above and avoid a reorder if all 4 motors draw current together — 4× 2A would be 8A peak, but they rarely all stall simultaneously, so 5A is a reasonable working budget with headroom, not a hard minimum. RAMPS 1.4 has its own screw-terminal power input, so no separate barrel jack adapter is needed — if the supply ends in a barrel plug, cut it off and wire the bare leads straight into RAMPS's terminal (or get a supply with bare leads/screw terminals to begin with). |

## Inter-unit cable and connectors

Per `control/sequence.md`'s Mounting section: only logic signals + motor
power cross the cable, drivers stay local to each motor. **(Superseded by
revision 2026-10-08.1: all four drivers are on the RAMPS; only the key motor's
own cable runs to the key turner.)**

| Item | Qty | Est. unit price | Est. total | Status | Notes |
|---|---|---|---|---|---|
| Multi-conductor cable, 6–8 conductor | ~1–2m | €3–8/m | €3–15 | ✅ Ordered (Order 2, QUARKZMAN 22AWG shielded, 6-conductor, 18ft/~5.5m, €23.69) | Needs to carry step/dir/enable + UART (4 signal lines) plus motor power (2 lines) to the key-turner unit. **Settled 2026-10-06** (`control/wiring.md` §4): 12V, GND, 5V logic, STEP, UART, DIAG; the remote driver's EN and DIR are tied low on its board and handled over UART. Ordered length (~5.5m) is well over the 1–2m estimate — fine as a bulk roll, just explains the higher line cost than estimated. Shielded, 22AWG — heavier gauge than the "cheap alarm cable" fallback originally considered, comfortably covers motor current. |
| JST-XH connector pair (or similar keyed connector), 8-pin | 2 | €1–3 | €2–6 | ⚠️ Substituted (Order 3, Ausi 5.08mm 8-pin Phoenix screw-terminal connectors, €13.99) | One pair per end, so the key-turner unit can be unplugged for repositioning as noted in the mounting doc. What arrived is a Phoenix-style screw-terminal connector rather than JST-XH — still detachable and keyed, arguably more robust for the motor-power conductors, but a different part than specified here. Flagging for awareness, not necessarily a problem. |

## Filament (final motorized coupler only — not the hand-test keys)

| Item | Qty | Est. price | Status | Notes |
|---|---|---|---|---|
| PETG-CF or nylon filament, small spool | 1 | €25–40 | ✅ Ordered (Bambu Lab, PETG-CF Black 1kg, €33.27) | Wear-resistance mitigation from `docs/decisions.md`'s closed tooth-geometry decision — only needed for the coupler that will actually do the ~8,000-attempt motorized search, not the plain-PETG hand-test keys already printed. PETG-CF branch chosen (not nylon). |
| Hardened (steel/ruby-tipped) nozzle, if not already owned | 1 | €10–20 | ✅ Ordered (Bambu Lab, Tungsten Carbide Hotend – H2/P2S/X2D, €60.49) | CF-filled filament is abrasive and will wear a brass nozzle quickly. What was ordered is a full tungsten-carbide hotend assembly (H2D-specific) rather than just a nozzle tip, hence the higher cost vs. the €10–20 estimate — same purpose, tungsten carbide is even more wear-resistant than ruby-tipped. |

## Mounting

| Item | Qty | Est. price | Status | Notes |
|---|---|---|---|---|
| Wukong 22mm rubber-coated pot magnets, M4 threaded back, listed 6mm tall | 9 (6 dial unit + 3 key turner) + spares | €19.99 / 20-pack (B0DGQ52DY9) or 10-pack (B0D5B4TJ7B) | ✅ Ordered (Paul, 2026-10-06) | Replaces the 2mm×8mm press-fit discs below on **both** units (see `docs/housing_decisions.md`, 2026-10-06 rubber-magnet entry). Each drops into a through hole (nothing printed over air, so no strings to dig out), sits on a printed seat ring, and is held by a printed retainer disc (`print_magnet_retainer.scad`, 10 per print) clamped by an M4 screw into the magnet's threaded back — use the screws if the pack includes them, otherwise M4 flat/pan head, length = 3mm retainer + the magnet's thread depth (measure it; don't bottom the screw). Rubber face stands 0.2mm proud of the plate. Published figures for similar magnets put rubber-coated shear grip at ~31–38% of pull vs ~15% bare — roughly 2x the sideways grip of a bare magnet for the same pull, which is what holds a unit on a vertical door. No pull rating on the listing: **on arrival, measure diameter / height / thread depth and do a one-magnet sideways pull test with the luggage scale** before trusting the units on the door. If the listed 22×6 is off, change `rmag_d` / `rmag_h` in `common_mounts.scad` and re-render. |
| ~~Neodymium disc magnets, 2mm×8mm~~ (superseded 2026-10-06 by the rubber magnets above) | already on hand (~100) | €0 | ✅ On hand, no longer used for mounting | Door confirmed ferrous 2026-09-29 (both body and door), so magnets are the mounting method. Paul already has enough on hand from a prior print project, which also worked out the press-fit pocket geometry to reuse: **8.00mm diameter × 1.9mm depth** per magnet, in both units' mounting faces. No purchase needed. **Update 2026-10-04**: the dialer base plate's door-facing face now has **135** pockets (`magnet_pts` in `dial_unit_housing.scad`, so Paul can experiment with magnet/screw mixes on the door) — more than the ~100 on hand, and the key-turner unit needs some too. Either leave some pockets empty or buy more 2mm×8mm discs (same size, same press-fit pocket). Press them in with consistent polarity facing out. |
| M3 brass heat-set threaded inserts (4.2mm OD, ~5mm length) | 3 (+ spares) | €8.99 | ✅ Ordered (HANGLIFE M3 knurled brass insert kit, 100pcs, Amazon.fr "HANGLIFE Thread Inserts for Hot Melting, M3 Threaded Insert", €8.99) | New with `dial_unit_housing.scad` v0.3/v0.4 (see `docs/housing_decisions.md`) — the housing's `frame()` was split into 3 bolt-together tiers (`front_assembly()` / `rear_assembly()` / `electronics_deck()`) to fix unsupported bridges Bambu Studio flagged, and a real fouled-motor collision on the printed v0.3 part. One insert per standoff leg, 3 legs joining front-to-rear (`front_standoff_legs()`). ~5mm length fits the 6mm-deep leg bore with a little clearance; a small multi-size kit covers this and is useful elsewhere. **Qty dropped from 6 to 3** by the 2026-10-03 motor-sled rework: the OTHER 3 (rear-to-deck, `deck_standoff_legs()`) switched to a direct M5 self-tap screw instead of M3+insert (see `docs/housing_decisions.md`) — this kit is still needed for the front joint, `electronics_deck()`'s Mega posts, and general shop stock. **Update 2026-10-04**: the front-to-rear joint no longer uses these (it moved to M6 countersunk self-tap screws, same as the deck joint — see the M6 row and `docs/housing_decisions.md`). They're now only needed if the first printed front leg splits (fallback) and for general shop stock; nothing to re-order. |
| M3×8 DIN 912 / ISO 4762 socket-head cap screws | 3 (+ spares) | €12.99 | ✅ Ordered (Taiss M3 screw kit, 550pcs, M3x6/8/12/16/20/25/30mm, 304 stainless, hex socket head, Amazon.fr "Taiss 550pcs M3 Screw Kit", €12.99) | Pairs with the inserts above — 3 through `motor_plate()`'s counterbored holes into the front legs' inserts (`front_standoff_legs()`). Machine-thread, not self-tapping (threads into the brass insert). **M3x8, not x10/x12**: a longer screw bottoms on the leg's solid floor before its head seats flush — max before that happens is ~8.8mm — see the print notes in `dial_unit_housing.scad` for the math. **Qty dropped from 6 to 3**: the deck joint now uses M5 (see row below), so only the front joint's 3 screws come from this kit — the kit's other 6 lengths (M3x6/12/16/20/25/30) are still useful elsewhere in the build. **Update 2026-10-04**: no longer used for the front-to-rear joint (now M6 countersunk, see below); kit stays useful for general shop stock. |
| M6 self-tapping screws, countersunk head, ~13–16mm (M6x15 nominal) | 6 (+ spares) | €0 | ✅ On hand (Paul's existing M5/M6 assortment box, same one bench-tested in `standoff_screw_fit_test.scad`) | New with the 2026-10-03 motor-sled rework — replaces M3+insert for `deck_standoff_legs()` (rear-to-deck joint) only. **M6, not M5**: corrected after `standoff_screw_fit_test.scad`'s real bench results (logged just above/below in `docs/housing_decisions.md`) showed M5 didn't self-tap at all, while M6 at a 5.4mm pilot worked cleanly. Self-taps directly into that 5.4mm pilot hole (`m6_selftap_pilot_d`), no insert needed. Countersunk chosen over pan head for repeatable, self-centering shaft alignment — both head styles tested fine. **Caveat**: the 5.4mm pilot was only bench-tested in a thicker-walled test coupon than the real leg (`leg_dia` 12mm leaves ~3.3mm wall here, vs. ~6.3mm tested) — thread the first one in by hand, not a power driver, and check for cracking. No purchase needed if the on-hand assortment box has countersunk M6 in this length range; if not, buy a small pack. **Update 2026-10-04**: quantity 3 → 6 — the front-to-rear joint (3 screws through `motor_plate()` into `front_standoff_legs()`) now uses the same M6 countersunk self-tap screws as the deck joint, for the same self-centering reason. Length ~15–16mm (6mm plate + ~10mm engagement; max before bottoming is 18mm). The M6 pilot in the 12mm front legs is the same ~3.3mm-wall case as the deck legs, which took these screws fine on Paul's 2026-10-03 print. |

## Optional / contingency

| Item | Qty | Est. unit price | Est. total | Status | Notes |
|---|---|---|---|---|---|
| AS5600 magnetic encoder breakout | 1 | €2–5 | €2–5 | ✅ Ordered (Order 1, AS5600 ×4, €9.86) | Only needed if bench testing shows the printed coupler slipping under torque on key-4's angle count. Cheap enough to buy speculatively; `control/sequence.md` flags it as an easy later add-on rather than a day-one requirement. Ordered 4 rather than 1 — extra spares. |
| Momentary pushbutton (dialing-trigger switch) | 1 | €1–2 | €1–2 | ✅ Ordered (Order 2, Lewttyer 7mm pushbutton ×12, €10.90) | For "triggered by a physical switch" in the operating sequence, if that's preferred over a serial/USB command to start a run. Ordered a 12-pack rather than 1 — extra spares. |

## Prototyping basics (skip anything already on hand)

Called out explicitly since the goal is one order, not a string of
"oh, also need..." trips back to a supplier:

- ✅ **Small perfboard or a couple of 2/3-pin screw terminal blocks** — Ordered (Order 1, RUNCCI-YUN 82pc double-sided PCB kit, €12.98; also see the Phoenix screw-terminal connectors in Order 3, which can double as terminal blocks). For the key-turner unit — it has no shield to plug into, so its driver's STEP/DIR/ENABLE/DIAG/UART/power connections from the cable need a small hand-wired board rather than a socket.
- ⚠️ **Jumper wire assortment** (M-M, M-F, F-F) — Partially ordered: two M–M kits (Order 2, GTIWUNG 150pcs + a 560pc breadboard kit, €11.99 + €8.99), but **no M-F or F-F jumpers**. Still needed for the RAMPS DIAG-to-endstop-header wiring, the UART tap to `Serial2`, and general point-to-point connections — worth a small follow-up order.
- ⚠️ **Soldering iron + solder** — Iron ordered (Order 2, Yofuly 75W soldering station, €49.99); solder wire itself unconfirmed — check what's in the kit on arrival. **Update 2026-10-07: solder and solder wick came with it.**
- ✅ **A basic multimeter** — Not ordered; **Paul already has one** (2026-10-07). Useful for checking continuity on the inter-unit cable and current-limit setup on the drivers.
- ✅ Heat shrink tubing, small assortment — Ordered (Order 1, 800-piece assortment, €8.99).
- ✅ USB cable for the Arduino Mega — Ordered (Order 2, GIANAC USB-C→USB-B, 2m, €5.99) — matches the genuine Mega 2560's USB-B port, assuming USB-C on the computer end.

Not on the original list, added during ordering: a heat gun (Order 2, €16.39) — useful for shrinking the heat-shrink tubing above.

## Rough total

Core electronics (motors, drivers, Mega, RAMPS shield, resistors — all
now priced against real listings) + power + cable/connectors + filament
+ optional AS5600 and switch: **roughly €150–245**, plus ~€20 for
mounting (Wukong rubber magnets, 2026-10-06), plus whatever's missing from the
prototyping-basics list above (perfboard, jumper wires, soldering iron,
multimeter — skip anything already owned).

**Actual spend so far (2026-09-29, across all four orders): €775.74**,
including €60.49 for the tungsten-carbide hotend and €291.43 for the
AMS 2 Pro / general filament restock — both well above the original core
estimate since they weren't priced against real listings when this total
was first drafted, and the AMS 2 Pro isn't a BOM item at all.

## Single-order readiness

Everything on this list has now been ordered across four orders placed
2026-09-29, **except**:
- ~~a multimeter (not ordered anywhere)~~ Paul already has one (2026-10-07)
- M-F / F-F jumper wires (only M-M was ordered)
- ~~solder wire (unconfirmed — check the soldering station kit on arrival)~~ came with the station (Paul, 2026-10-07)

The JST-XH connector was substituted with a Phoenix screw-terminal
connector (see Order status above) — not a gap, just a part swap worth
noting.

The only previously-open item, torque/effort to turn each dial wheel and
the key, is still hedged rather than blocking: the higher-torque NEMA17
pick and the 5A supply above both build in headroom against an
unmeasured load, so the plan is to bench-test once hardware arrives and
only revisit if that headroom genuinely isn't enough — at which point
gearing, not a different motor class, is the likely fix.

## Added 2026-10-04: Mega base-plate mount

| Item | Qty | Cost | Status | Notes |
|---|---|---|---|---|
| M3 screws, ~6-8mm, self-tapping into PETG | 4 (+ spares) | €0 | ✅ On hand (the Taiss M3 kit's M3x6/x8) | For `electronics_deck()` in base-plate mode: 4 screws through the Mega's own plastic base into 2.6mm pilot holes. Now the only Mega mounting (coupon check passed 2026-10-04, 3 of 4 screws go in; 3 are enough). |
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

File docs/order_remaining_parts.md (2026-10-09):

# Ordering the remaining parts: amazon.fr vs mouser.fr (2026-10-07)

> **Revision 2026-10-09.1** · order history; key driver on the RAMPS E0 socket, UART pigtail — the hub-board parts here are spares now · log: `docs/revisions.md`

**Revision 2026-10-08.1 (2026-10-08):** a record of the 2026-10-07 order.
Some of these parts — the PTC fuse, the 100 µF capacitors, and (elsewhere) the
6-conductor cable and Phoenix connectors — are **no longer used** now that the
key driver is in the RAMPS E0 socket. They were bought; keep them as spares.
Nothing here needs re-ordering. See `docs/revisions.md` and `docs/bom.md`.

This covers everything still marked 🛒 in `docs/bom.md` ("Electronics
assembly — every discrete part", table A), plus the three tools on its
"Still to buy" list (multimeter, solder, flush cutters).

**Status (2026-10-07): ordered.** Paul placed the amazon.fr order: items
1, 2 and 5–8 of Table 1, with these changes (Paul's screenshots):
- **Capacitor:** Innfeeltech 100 µF 35 V radial, 50 pcs, €7.49, delivery
  Friday 9 Oct, instead of item 2. It isn't sold as low ESR
  (`control/wiring.md`, log 2026-10-07).
- **PTC fuse:** which listing isn't recorded. None arrives soon, so a
  **1.6 A T (slow-blow) 5 × 20 mm glass fuse** stands in for hub F1 until
  it does: AUKENIEN 120-piece slow-blow kit, 5 × 20 mm, 250 V, €15.99,
  Prime next day.

**How the prices were found:** both sites block page views from the cloud
session, so every price and stock figure below comes from **web-search
snapshots**, not from the live pages. Treat them as a guide, and **check
price, stock and seller on each page before you order.**
- **amazon.fr** prices are in EUR, including VAT, as the search snapshot
  showed them.
- **mouser.fr**: only one EUR price came through (the multimeter). Every
  other Mouser price is **USD from mouser.com**; the French price will
  differ and may be shown without VAT.
- Mouser links marked ⇄ were built from a mouser.com result. If one fails,
  search the part number on mouser.fr.

## Recommendation

- **One order that covers everything: amazon.fr.**
  - Items 1, 2 and 5–8: **€53.13**, plus €7 delivery on the fuse.
    (Correction, 2026-10-07: the search snippet said €2; Paul's basket
    shows €7.)
  - Items 1 and 2 ship slowly from their sellers. Alternates are under
    "If the fuse or capacitor ships too slowly" below. Neither part is
    needed before bring-up stage 5.
  - Most picks are generic, unbranded parts. That's fine for this use.
- **mouser.fr** has branded parts (Bourns, Panasonic, Würth, Samtec,
  Adafruit) and real stock counts.
  - It has no 20 AWG wire in a sensible length: the smallest spool found
    is 100 ft, at about $96 a colour. So it can't cover everything in one
    order.
  - The parts come to about $21 at mouser.com prices. That's under the
    €75 free-delivery threshold, so delivery would be charged (the amount
    wasn't found).
- **Checked (Paul, 2026-10-07), so items 3, 4 and 9–12 aren't needed:**
  - the **header strips** (male and female) came with another order;
  - the Phoenix pack holds **5 headers + 5 plugs**: 2 + 2 needed, 3 + 3
    spare;
  - the soldering station came with **solder and solder wick**;
  - Paul **has flush cutters** and **a multimeter**.

  **The order is items 1, 2 and 5–8.**
- **Why the DC-jack adapter (item 6):** the PSU ends in a barrel *plug*,
  but the hub's 12V IN and the RAMPS '5A' input are screw terminals. The
  adapter is the socket the plug goes into; two 20 AWG wires run from its
  screws to the hub.
  - Without it you'd cut the plug off and screw the bare leads in,
    identifying + with the multimeter. That's free but can't be undone.
  - Don't use the Mega's own barrel jack instead. It feeds only the Mega
    (VIN). The RAMPS motor rail would get no 12 V, because D1 conducts
    only from that rail to VIN (RAMPS KiCad netlist, `control/wiring.md`
    log 2026-10-07).

## Table 1 — amazon.fr

| # | Need | Pick (ASIN) | Pack | Price shown | Availability shown | Fit notes |
|---|---|---|---|---|---|---|
| 1 | PTC fuse, radial, 1.1 A hold, ≥ 16 V ×2 | 30V 1.1A resettable fuse, radial "Polyswitch" — [B0848QX3FS](https://www.amazon.fr/fusible-r%C3%A9armable-plomb-radial-Polyswitch/dp/B0848QX3FS) | 20 | €10.21 + €7 delivery (Paul's basket, 2026-10-07; the snippet said €2) | **31 Oct – 5 Nov** (Paul's basket, 2026-10-07); third-party seller (LingTongTrade) | radial, 30 V, 1.1 A: meets spec. Generic, no reviews |
| 2 | 100 µF ≥ 25 V low-ESR electrolytic ×2 | Elna RJH 35 V 100 µF, 8 × 12 mm — [B07H9BKFGF](https://www.amazon.fr/Condensateur-%C3%A9lectrolytique-Electrolytic-Capacitor-Elna/dp/B07H9BKFGF) | 20 | €9.46 | in stock, free delivery **14–16 Oct** (Paul's basket, 2026-10-07); sold by IT-Tronics GmbH | RJH is a low-impedance series. 3.5 mm lead pitch: bend the leads to fit the perfboard. Alternative: sourcing map low-ESR 35 V, 6.3 × 7 mm, 50 pcs, €9.99 — [B07LDZ5HF8](https://www.amazon.fr/sourcing-map-Radial-Faible-Resist/dp/B07LDZ5HF8) |
| 3+4 | **Not needed** (from another order) — header strips | IZOKEE male + female 40-pin kit — [B07DBY753C](https://www.amazon.fr/IZOKEE-Connecteur-Femelle-Broches-Prototype/dp/B07DBY753C) | 15 + 15 strips | €11.71 | not shown | 4.6/5 (683). Female strips don't snap: cut them with the flush cutters (you lose one pin per cut). One strip gives 2 × 8 + 1 × 2 |
| 5 | F–F jumpers 10–20 cm, ~20 | ELEGOO 120 Dupont wires, 20 cm (40 F–F) — [B01JD5WCG2](https://www.amazon.fr/Elegoo-Multicolore-M%C3%A2le-Femelle-M%C3%A2le-M%C3%A2le-Femelle-Femelle/dp/B01JD5WCG2) | 120 | €8.99 | not shown | 4.7/5 (2,811) |
| 6 | DC jack, female 5.5 × 2.1 mm → screw terminal | LitaElek 5.5 × 2.1 adapters — [B019HAC6V4](https://www.amazon.fr/LitaElek-Femelle-Adaptateur-Connecteur-dispositifs/dp/B019HAC6V4) | 5 female + 5 male | €8.99 | not shown | 4.5/5 (1,235), 3 A. Check + / − with the multimeter before first use |
| 7 | 20 AWG wire, red + black, ≥ 1 m each | QUARKZMAN 20 AWG 2-core PVC, red/black, 4.5 m — [B0CW9M53BS](https://www.amazon.fr/QUARKZMAN-Parall%C3%A8le-Conducteurs-Longueur-Diam%C3%A8tre/dp/B0CW9M53BS) | 4.5 m pair | €9.49 | "only 3 left" (snippet) | true 20 AWG, tinned copper. The cores peel apart |
| 8 | Zip ties ~100 mm | Gocableties 100 × 2.5 mm, black — [B072SLJR2T](https://www.amazon.fr/Gocableties-100-colliers-serrage-nylon-robuste/dp/B072SLJR2T) | 100 | €5.99 or €4.99 (snippets differ) | not shown | 4.5/5 |
| 9 | **Not needed** (5 + 5 on hand) — 5.08 mm 8-pin pluggable terminal | no reliable listing — see Table 3 | — | — | — | — |
| 10 | **Not needed** (Paul has one) — multimeter | **budget:** UNI-T UT33D+ — [B08W36VF6H](https://www.amazon.fr/UNI-T-UT33D-MIE0328-Miernik-Uniwersalny/dp/B08W36VF6H) · **better:** Fluke 101 — [B00V6BBRNQ](https://www.amazon.fr/Fluke-Multim%C3%A8tre-num%C3%A9rique-poche-101/dp/B00V6BBRNQ) | 1 | UT33D+ €22.23 · Fluke 101 €77.38 (other sellers from €65.01) | UT33D+: free delivery, "Amazon's Choice" | UT33D+: 4.6/5 (144), buzzer, diode test, manual ranging. Fluke 101 has a continuity beeper and DC V (Fluke spec) |
| 11 | **Not needed** (came with the station) — solder, ~0.8 mm | 63/37 rosin core 0.8 mm, 4 × 50 g — [B09L412D4X](https://www.amazon.fr/souder-colophane-bricolage-%C3%A9lectronique-paquet/dp/B09L412D4X) | 200 g | €14.99 | not shown | leaded. 4.3/5 (17 reviews only). Lead-free alternative: GTSE Sn99.3Cu0.7, 100 g, 4.5/5 (537) — [B08GGBT378](https://www.amazon.fr/GTSE-souder-colophane-soudure-%C3%A9lectrique/dp/B08GGBT378), €6.59–18.49 (snippets differ) |
| 12 | **Not needed** (on hand) — flush cutters | Knipex 78 61 125 SB Electronic Super Knips — [B000OIB7J6](https://www.amazon.fr/Knipex-78-61-125-SB/dp/B000OIB7J6) | 1 | €25.99 | not shown | 4.7/5 (3,695). Alternative: Hakko CHP-170, €24.31 — [B00FZPDG1K](https://www.amazon.fr/Hakko-CHP-170-Pince-coupe-fil-souple/dp/B00FZPDG1K) |

**Totals at the prices shown:**
- **The order (1, 2, 5–8): €53.13**, plus €7 delivery on the fuse (the
  snippet said €2; corrected 2026-10-07).
  Without the DC-jack adapter it's €44.14. Either is over the €35
  free-delivery threshold for the items Amazon ships itself.
- For the record:
  - €64.84 before the header strips were ruled out;
  - before items 9–12 were ruled out:
    - €87.07 with the UT33D+ (€142.22 with the Fluke);
    - before that, €128.05 with UT33D+, solder and Knipex (€183.20 with
      the Fluke).

**Free delivery** is over €35, but only for items sold or shipped by
Amazon ([help page](https://www.amazon.fr/gp/help/customer/display.html?nodeId=GZXW7X6AKTHNUP6H)).
Some picks look like third-party sellers, so check "Expédié par Amazon" on
each.

### If the fuse or capacitor ships too slowly (2026-10-07)

Paul's basket showed the fuse (item 1) arriving 31 Oct – 5 Nov and the
capacitor (item 2) 14–16 Oct, both from third-party sellers.

**Neither part holds up bring-up stages 0–4.**
- F1 feeds only the cable's 12 V to the key turner: hub 12V IN + → F1 →
  Phoenix pin 1 (`control/wiring.md` §5).
- C1 sits on the remote (key) driver board.
- Stages 0–4 use the dial drivers only; stage 4b says "the key turner is
  not needed yet". Leave F1's place on the hub empty until then, so the
  cable carries no 12 V.
- Both parts are first needed at **stage 5 (key turner)**.

So the slow listings may be fine. If you'd rather have them sooner, these
also meet the spec. **Delivery dates weren't visible from here**, so pick
whichever shows "Expédié par Amazon" or the earliest date in your basket.

**PTC fuse.** On a multi-value listing, select the **1.1 A** variant. The
part code ends in **110**, as in RUEF110 or JK30-110, meaning 1.10 A hold.
It needs 2 radial leads and a rating of ≥ 16 V. All the 30 V and 72 V
packs below have margin.

| Pick (ASIN) | Pack | Notes |
|---|---|---|
| JK30 30 V PPTC, radial ("DIP") — [B0D56N2RWZ](https://www.amazon.fr/Fusible-r%C3%A9initialisable-polym%C3%A8re-PPTC-pi%C3%A8ces/dp/B0D56N2RWZ) | 10 | **select 1.1 A** (the link may open on 0.5 A) |
| COJIC JK30 30 V PPTC, radial — [B0CPVKHC3L](https://www.amazon.fr/COJIC-PI%C3%88CES-fusible-r%C3%A9initialisable-polym%C3%A8re/dp/B0CPVKHC3L) | 10 | **select 1.1 A** |
| MYRRHE 30 V, RUEF110 option — [B0CPVDXLJQ](https://www.amazon.fr/MYRRHE-fusibles-r%C3%A9armables-enfichables-r%C3%A9armable/dp/B0CPVDXLJQ) | 10 | **select RUEF110 1.1 A** |
| FESTAS 30 V 1.1 A — [B0D4HMVP13](https://www.amazon.fr/Fusibles-r%C3%A9initialisables-thermistance-polym%C3%A8re-auto-r%C3%A9cup%C3%A9ration/dp/B0D4HMVP13) | 10 or 40 | **select 1.1 A** |
| RXEF 72 V assortment, 10 values × 5 pcs, includes 1.1 A — [B0C5SMK827](https://www.amazon.fr/Valeurs-Pi%C3%A8ces-fusible-auto-r%C3%A9armable-s%C3%A9rie/dp/B0C5SMK827) | 50 | no variant to pick; spare values for later |
| RGEF110, 16 V, 1.1 A — [B0DPC8W6GK](https://www.amazon.fr/Fusible-r%C3%A9initialisable-pi%C3%A8ces-RGEF110-fusible/dp/B0DPC8W6GK) | 50 | meets ≥ 16 V with no margin; prefer a 30 V one |

**Capacitor.** Keep it **low ESR**. The TMC2209 datasheet (§3) recommends
low-ESR electrolytics for VS filtering, with at least 100 µF near the
driver. Plain "100 µF 35 V" packs (no low-ESR claim) are a last resort.

| Pick (ASIN) | Pack | Notes |
|---|---|---|
| sourcing map low-ESR 100 µF 35 V, 105 °C, 6.3 × 7 mm — [B07LDZ5HF8](https://www.amazon.fr/sourcing-map-Radial-Faible-Resist/dp/B07LDZ5HF8) | 50 | ~€9.99 (snippet). **First choice.** A 6.3 mm can normally has 2.5 mm lead spacing, which fits the perfboard without bending |
| "faible ESR / haute fréquence" 100 µF 35 V, 6 × 12 mm — [B0CS34JZG2](https://www.amazon.fr/condensateur-%C3%A9lectrolytique-Industrial-Electrical-capacitors/dp/B0CS34JZG2) | 20 | unbranded; low ESR is the seller's claim |

Whichever you get, check the polarity when you fit it: the stripe marks −.

## Table 2 — mouser.fr

| # | Need | Part (manufacturer MPN, link) | Order qty | Price shown | Stock shown | Notes |
|---|---|---|---|---|---|---|
| 1 | PTC fuse ×2 | Bourns **MF-R110**, radial, 1.1 A hold / 2.2 A trip, 30 V — [⇄ link](https://www.mouser.fr/ProductDetail/Bourns/MF-R110?qs=wd8kHz0doL7LkwIbzZb5mA%3D%3D) | 2 | ~$0.40 each (mouser.com, unreliable) | 19,054 | alternative: Littelfuse RUEF110 — [⇄ link](https://www.mouser.fr/ProductDetail/Littelfuse/RUEF110?qs=hv6pn79dJPSNtwKNbPwPHQ%3D%3D) |
| 2 | 100 µF ≥ 25 V low ESR ×2 | Panasonic **EEU-FR1E101**, 25 V, 6.3 × 11.2 mm, 2.5 mm pitch, 130 mΩ — [⇄ link](https://www.mouser.fr/ProductDetail/Panasonic/EEU-FR1E101?qs=Ao3mORb5HCDieoJwtkb8Dw%3D%3D) | 2 | $0.45 each (mouser.com) | 19,980 | alternative: Rubycon 35ZLH100MEFC6.3X11 (35 V) — [⇄ link](https://www.mouser.fr/ProductDetail/Rubycon/35ZLH100MEFC6.3X11?qs=T3oQrply3y8xzyooRx3RZg%3D%3D) |
| 3 | **Not needed** — male header ≥ 13 pins | Würth **61302011121**, 1 × 20, 2.54 mm, gold — [⇄ link](https://www.mouser.fr/ProductDetail/Wurth-Elektronik/61302011121?qs=PhR8RmCirEbj/FsnpbhNaw%3D%3D) | 2 | $1.23 each (mouser.com) | 1,288 | |
| 4 | **Not needed** — female sockets 2 × (1 × 8) + 1 × (1 × 2) | Samtec **SSW-108-01-G-S** (1 × 8) — [⇄ link](https://www.mouser.fr/ProductDetail/Samtec/SSW-108-01-G-S?qs=FESYatJ8odLaL9GxbCQJ2g%3D%3D) and **SSW-102-01-G-S** (1 × 2) — [⇄ link](https://www.mouser.fr/ProductDetail/Samtec/SSW-102-01-G-S?qs=92ilVni64gwMaw8Iglb9kA%3D%3D) | 2 + 1 | 1 × 8: $1.76 each (mouser.com); 1 × 2: not shown | 1 × 8: 6,306 | |
| 5 | F–F jumpers ~20 | Adafruit **4447**, silicone F–F, 200 mm, 40 pcs — [⇄ link](https://www.mouser.fr/ProductDetail/Adafruit/4447?qs=CUBnOrq4ZJzovVmrsSU55g%3D%3D) | 1 | $9.95 (mouser.com) | 724–1,513 | |
| 6 | DC jack adapter, female | SparkFun **PRT-10288** "DC Barrel Jack Adapter – Female" — [⇄ link](https://www.mouser.fr/ProductDetail/SparkFun/PRT-10288?qs=WyAARYrbSnbv/ypDwaDLyg%3D%3D) | 1 | $2.95 (mouser.com) | 101 | **VERIFY 5.5 × 2.1 mm and screw terminals** on the page |
| 7 | 20 AWG wire, ≥ 1 m red + black | Alpha Wire 3053 RD005 / BK005, 100 ft spools | — | ~$96 per spool (mouser.com, a 3053 variant) | 239–251 | **not sensible for 2 m** (see Table 3) |
| 8 | Zip ties | Panduit **PLT1M-M**, 99 mm, natural — [⇄ link](https://www.mouser.fr/ProductDetail/Panduit/PLT1M-M?qs=PijdWQvv7l82QBSPSSlofg%3D%3D) | 100 | $0.064 each (mouser.com) | 709,949 | |
| 9 | **Not needed** (5 + 5 on hand) — Phoenix 8-pin, header + plug | header MSTBA 2,5/8-G-5,08 = **1757307** — [⇄ link](https://www.mouser.fr/ProductDetail/Phoenix-Contact/1757307?qs=o3rrLWFGhRl4IvmrdyQ5FA%3D%3D); plug MSTB 2,5/8-ST-5,08 = **1757077** (no page seen) | 2 + 2 | not shown | not shown | genuine Phoenix Contact |
| 10 | **Not needed** — multimeter | Extech **EX330** (Mouser 685-EX330), autoranging, 600 V DC, continuity — [⇄ link](https://www.mouser.fr/ProductDetail/Extech/EX330?qs=tv7vi16PWA4nsXR8adm%2Bmg%3D%3D) | 1 | **€66.39** ([mouser.fr listing](https://www.mouser.fr/Extech/Test-Measurement/Multimeters-Voltmeters/_/N-5gfo?P=1z13cd3)) | 11 | the only EUR price found. Alternative: Fluke 107 ESP, $160.99 |
| 11 | **Not needed** — solder | MG Chemicals **4900-35G**, SAC305 lead-free, 0.81 mm (Mouser 590-4900-35G) | 1 | $5.35 (old USD catalogue: may be stale) | not shown | no product page seen. Alternative: 4900-112G (¼ lb) — [⇄ link](https://www.mouser.fr/ProductDetail/MG-Chemicals/4900-112G?qs=YqNA2qefETAK87e3A6/Oig%3D%3D) |
| 12 | **Not needed** — flush cutters | Adafruit **152** (Hakko CHP-170) — [⇄ link](https://www.mouser.fr/ProductDetail/Adafruit/152?qs=N/3wi2MvZWC96jMaJ3xvTg%3D%3D) | 1 | $7.25 (mouser.com) | 588–621 | |

**Total:** about **$21** for items 1, 2, 5, 6 and 8 at mouser.com prices,
plus delivery (the order is under €75), plus the wire bought elsewhere.
- It was about $27 with the headers (items 3, 4).
- It was about $40 with items 11 and 12 as well.

Paul ruled those out on 2026-10-07.

**Shipping:**
- Free on most orders **over €75**
  ([mouser.fr help](https://www.mouser.fr/help/orders-shipping)).
- Ships the same day; delivery takes 2–5 days.
- The sale terms say prices exclude VAT; check at checkout.

## Table 3 — not found on either site

None of the **required** parts is missing from both sites: every one is on
at least one. What's left:

| Item | amazon.fr | mouser.fr | What to do |
|---|---|---|---|
| 5.08 mm 8-pin header + plug, with a price | generic listings only; the one price (€34.21, [B0D7714SNJ](https://www.amazon.fr/Bornier-enfichable-connecteur-5-08mm-femelle/dp/B0D7714SNJ)) doesn't say which variant | genuine Phoenix 1757307 + 1757077 found, no price | **not needed**: the Order 3 pack holds 5 + 5 (Paul, 2026-10-07) |
| 20 AWG wire in a short length | ✅ found (Table 1, #7) | ❌ only 100 ft spools (~$96 a colour) | Amazon, or any local electronics or DIY shop |
| Branded PTC fuse (Bourns / Littelfuse) | ❌ only generic 30 V 1.1 A packs | ✅ MF-R110, RUEF110 | generic is fine; Mouser if you want a brand |
| 4 mm standoffs (remote board) | not searched | not searched | thread and length wait for the remote-board mount design (`control/wiring.md` §6.2) |
| M3 × 3 / × 4 grub screws (optional, mechanical) | not searched | not searched | optional (`docs/bom.md`, dial unit v2) |

To let a future session read live amazon.fr / mouser.fr pages (current
price and stock), add `www.amazon.fr` and `www.mouser.fr` to the cloud
environment's allowed domains (network settings).

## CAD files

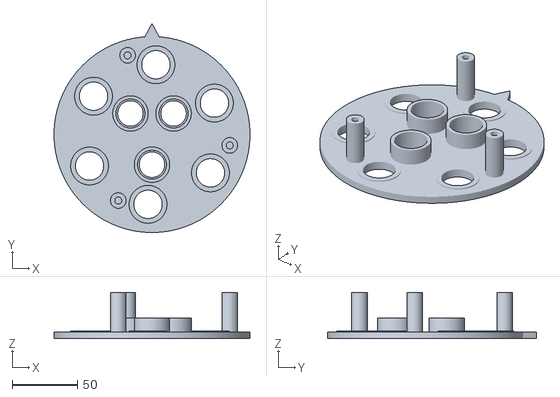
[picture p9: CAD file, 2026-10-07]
cad/dial_front_assembly.stl
150.0 x 160.0 x 35.5

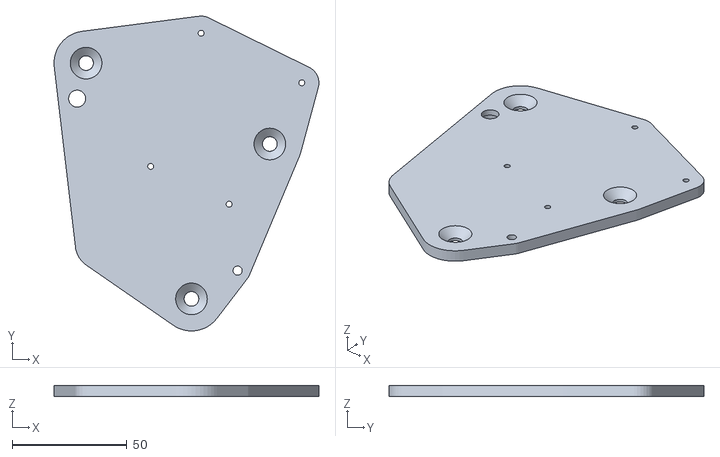
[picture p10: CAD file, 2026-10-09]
cad/electronics_deck.stl
115.7 x 137.5 x 5.00

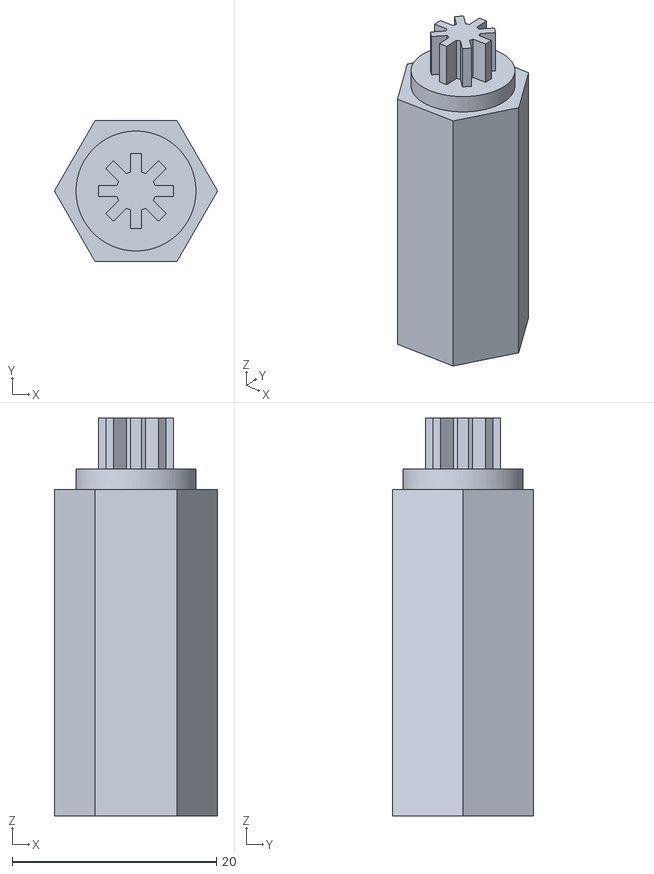
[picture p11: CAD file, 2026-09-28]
cad/renders/tube_socket_test_key_1.75-1.04.stl
16.0 x 13.9 x 39.0

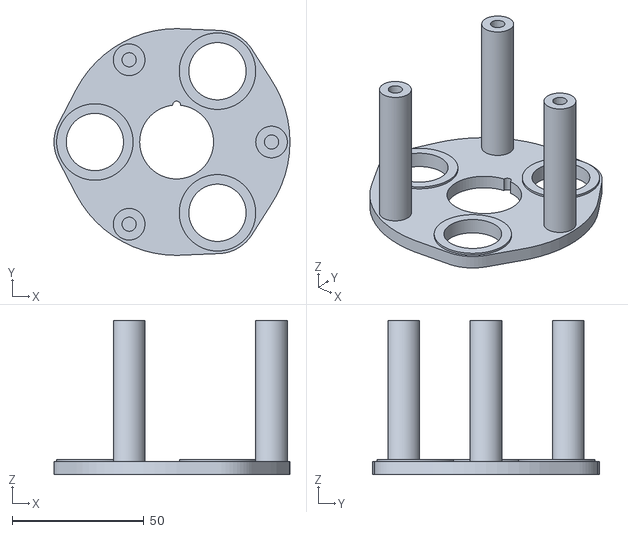
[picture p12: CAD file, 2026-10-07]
cad/key_turner_base.stl
89.5 x 86.0 x 58.5

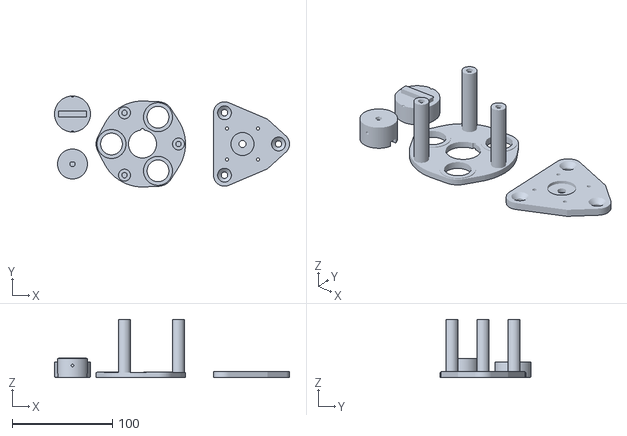
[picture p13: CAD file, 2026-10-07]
cad/key_turner_housing.stl
235.0 x 91.0 x 58.5

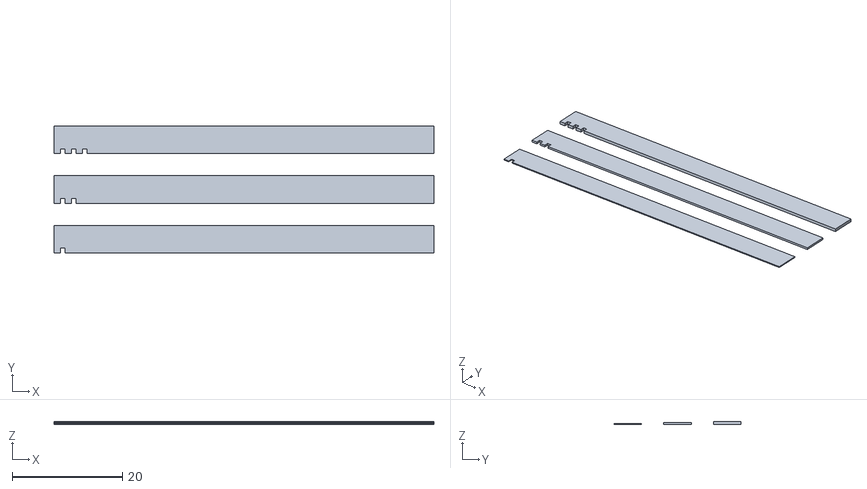
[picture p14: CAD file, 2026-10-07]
cad/magnet_wrap_strips.stl
69.0 x 23.0 x 0.6

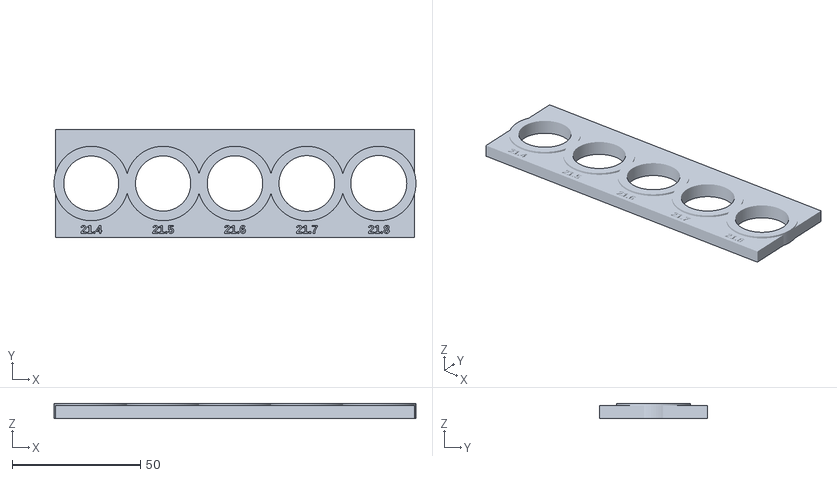
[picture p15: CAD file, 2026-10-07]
cad/magnet_fit_test.stl
141.0 x 42.0 x 5.80

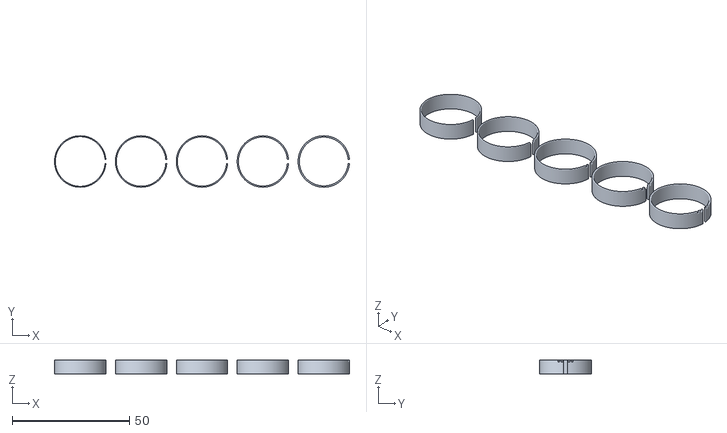
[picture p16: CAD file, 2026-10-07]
cad/magnet_split_sleeves.stl
126.0 x 22.0 x 5.80

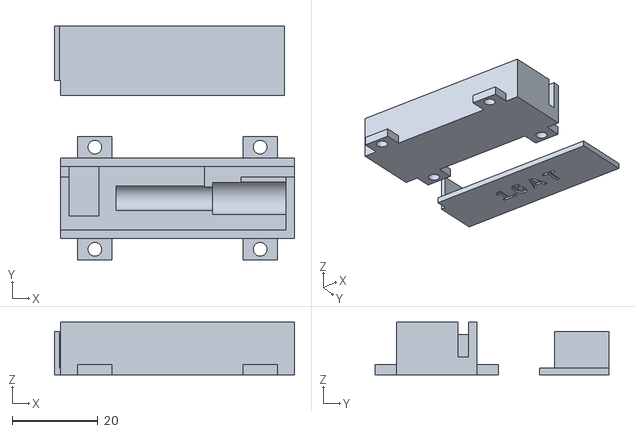
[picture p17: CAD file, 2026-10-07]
cad/fuse_holder.stl
55.9 x 54.4 x 12.2

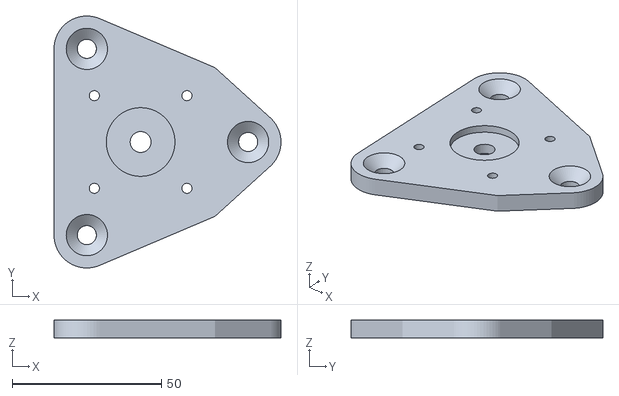
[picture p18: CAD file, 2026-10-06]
cad/key_turner_motor_plate.stl
76.0 x 84.4 x 6.00

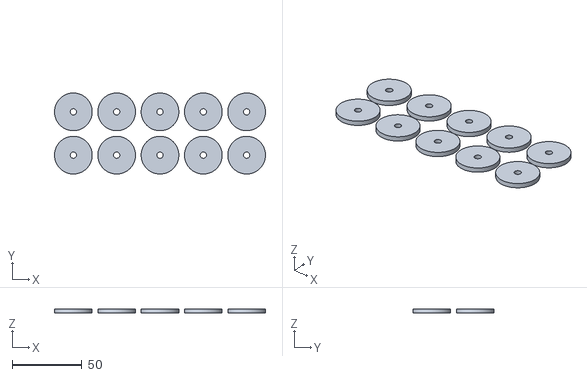
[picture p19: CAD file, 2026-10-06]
cad/magnet_retainers.stl
151.0 x 58.0 x 3.00

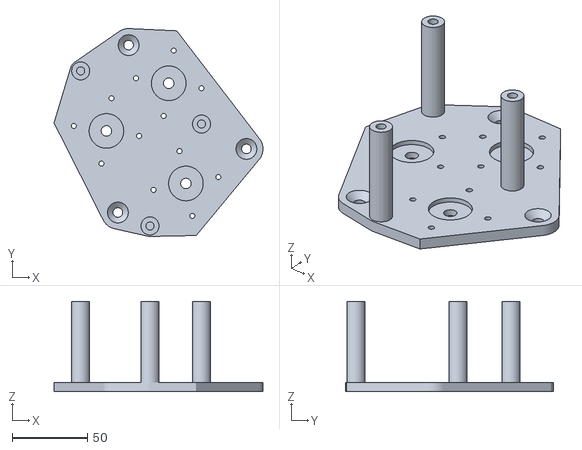
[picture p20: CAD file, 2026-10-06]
cad/dial_motor_sled.stl
138.7 x 138.0 x 60.0

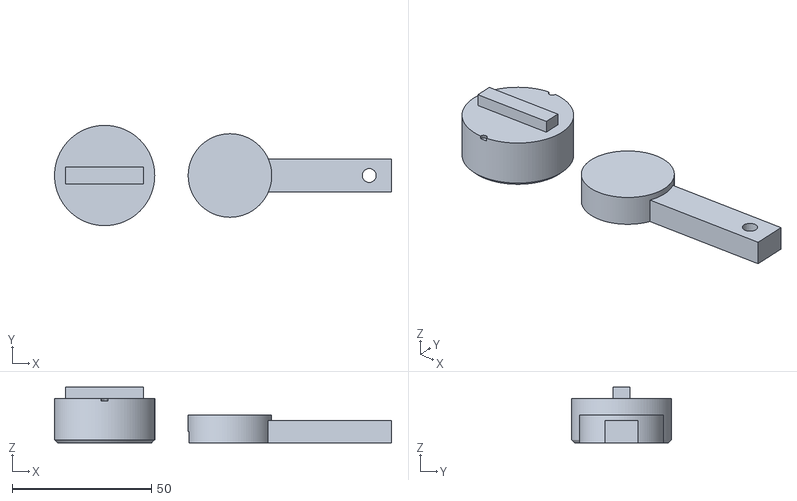
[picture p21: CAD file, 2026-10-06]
cad/key_fit_test.stl
121.0 x 36.0 x 20.0

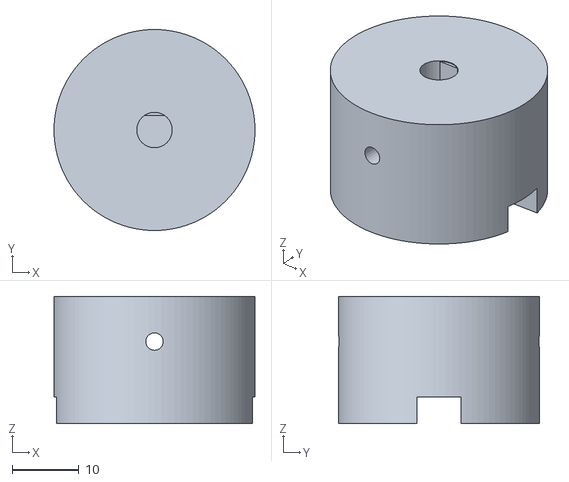
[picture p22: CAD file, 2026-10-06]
cad/key_turner_hub.stl
30.0 x 30.0 x 19.0

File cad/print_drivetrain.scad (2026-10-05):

// Print-ready export: 3 dial gear-shafts (gear face down, plug up) and
// 3 motor pinions (hub down, teeth up). PETG-CF, elephant-foot
// compensation ON.
//   openscad -o dial_drivetrain.stl print_drivetrain.scad
use <dial_unit_housing.scad>
print_drivetrain();

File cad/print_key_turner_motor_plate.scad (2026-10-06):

// Print-ready export: key-turner motor_plate (see key_turner_housing.scad)
use <key_turner_housing.scad>
print_motor_plate();

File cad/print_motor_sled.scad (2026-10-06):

// Print-ready export: the motor sled (rear_assembly()) with its 3 deck legs,
// INNER face (spring pockets, screw countersinks) down, legs up.
//   openscad -o dial_motor_sled.stl print_motor_sled.scad
use <dial_unit_housing.scad>
print_rear_assembly();

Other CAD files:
cad/key_turner_cap.stl
cad/dial_pattern_test.stl
cad/dial_drivetrain.stl
cad/mega_base_fit_test.stl
cad/common_mounts.scad
cad/Fichet_robot.3mf
cad/dial_unit_assembled.scad
cad/dial_unit_housing.3mf
cad/dial_unit_housing.scad
cad/dial_unit_housing.stl
cad/fuse_holder.scad
cad/key_turner_assembled.scad
cad/key_turner_housing.scad
cad/mega_base_fit_test.scad
cad/print_dial_pattern_test.scad
cad/print_electronics_deck.scad
cad/print_front_assembly.scad
cad/print_fuse_holder.scad
cad/print_key_fit_test.scad
cad/print_key_turner_base.scad
cad/print_key_turner_cap.scad
cad/print_key_turner_hub.scad
cad/print_magnet_fit_test.scad
cad/print_magnet_retainer.scad
cad/print_magnet_split_sleeves.scad
cad/print_magnet_wrap_strips.scad
cad/printed_thread_test.scad
cad/printed_thread_test.stl
cad/standoff_screw_fit_test.scad
cad/standoff_screw_fit_test.stl
cad/tube_socket_test_key.scad
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

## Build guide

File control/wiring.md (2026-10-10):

# Wiring harness — Mega 2560 + RAMPS 1.4 + 4 × BTT TMC2209 V1.3

> **Revision 2026-10-09.1** · all four drivers on the RAMPS (key in E0); UART pigtail replaces the hub board · log: `docs/revisions.md`

Written 2026-10-06 (cloud session, no hardware). Everything below is from the
sources listed at the bottom; anything I could not establish is marked
**ASSUMPTION** or **VERIFY** and gets a bench step in `control/bringup.md`.
The firmware (`control/firmware/`) is built on this pin map
(`safe_robot/pins.h`).
Decision log for this file is at the end (most recent first).

**Revision 2026-10-08.1 (2026-10-08):** the key driver moved from a remote
board at the key turner into the RAMPS **E0** socket. Sections 3.1, 3.5, 3.6
and 6 (the remote board and its cable) are retired; section 4 is now the key
motor's own cable; section 5 (hub) shrinks to the UART junction. Reasoning in
the decision log, 2026-10-08.

**Revision 2026-10-08.2 (2026-10-08):** the hub board is replaced by the
**UART pigtail** (section 5): six leads with female Dupont ends, R1 in line in
the TX2 lead, one solder splice. Same circuit. Its driver leads clip onto the
**top of each driver's RX pin**, and DIAG is a plain jumper on the top of the
DIAG pin (no soldering on the drivers; two snips each). Decision log,
2026-10-08 (pigtail) and 2026-10-08 (evening).

## Summary — what was decided

1. **One UART bus, one 1 kΩ resistor in total**: Mega TX2 (D16) → 1 kΩ → bus;
   RX2 (D17) straight on the bus; every driver's PDN_UART straight on the bus.
   This is the datasheet's own circuit (TMC2209 DS Fig. 4.1). *Correction* of
   `sequence.md`, which said one resistor per driver. Built as the **UART
   pigtail** (section 5, revision 2026-10-08.2).
2. **UART needs no soldering**: the BTT V1.3's PDN_UART pin (**RX**, the 4th
   pin) stands up through the top of the driver as a tall pin (Paul's drivers,
   2026-10-08). Clip a female Dupont onto the **top of each driver's RX pin**
   (section 3.3). Leave the MS3 jumper **off** (RX also sits in the socket's MS3
   position). *Revision 2026-10-08.2*: until then the tap was the RAMPS MS3
   jumper pin under the driver, which was never checked for room.
3. **Addresses by RAMPS jumpers**: X = none (addr 0), Y = MS1 (addr 1),
   Z = MS2 (addr 2), **E0 = MS1 + MS2 (addr 3, the key)**.
   **Never fit an MS3 jumper** (it would tie the UART line to 5 V).
4. **DIAG: two snips per driver, no soldering** (all four drivers): on Paul's
   V1.3s the two EN-end pins (DIAG and its neighbour) stick out both above
   and below the board. Cut the **bottom** ends flush, so nothing points down
   at the RAMPS, and clip a plain F–F jumper onto the **top of the DIAG pin**
   (section 3.3). *Revision 2026-10-08.2*: until then the docs assumed the
   pins pointed down only and had a lead soldered to the DIAG joint.
5. **DIAG pins moved to interrupt-capable Mega pins** (D2, D3, D18, D19).
   *Correction*: dial B's DIAG was planned on Y_MIN (D14), which has no
   `attachInterrupt` on the Mega, and the datasheet says DIAG is a *pulse*.
   Y_MIN now takes the start/stop button.
6. **Between the units runs only the key motor's own cable** (~1 m, 4 wires,
   from the motor to the RAMPS E0 motor header). *Revision 2026-10-08.1*:
   until then a 6-conductor cable carried 12 V, GND, 5 V, STEP, UART and DIAG
   to a remote driver board (sections 3.1, 4 and 6, now retired).
7. **The key driver has its own STEP, DIR and EN** from the E0 socket (D26,
   D28, D24), like the dial drivers. The UART direction workaround
   (GCONF.shaft) and the TOFF disable are gone (firmware v0.4).
8. **Fusing**: RAMPS's own 5 A polyfuse feeds all four drivers (every socket's
   VMOT). *Revision 2026-10-08.1*: the hub's 1.1 A fuse on a separate key
   branch is gone with the branch. 12 V goes from the PSU adapter straight
   into the RAMPS "5A" terminal; nothing else carries it.
9. **Currents**: dial drivers 1.0 A RMS (hold 0.5 A) until the dial torque is
   measured; key driver starts at 0.6 A RMS and is then set to 2 × the measured
   minimum that turns the key (bench stage 5).
10. **Power order**: everything plugged with power off; USB first, then 12 V;
    12 V off first. Never plug or unplug a motor with 12 V on (the key motor
    included: its cable runs between the units).

## 1. Pin map

Dial naming follows `cad/dial_unit_housing.scad`: **A = top-left, B =
top-right, C = bottom** (standing in front of the safe).

| Function | Mega pin | Where to connect | Source / note |
|---|---|---|---|
| Dial A STEP / DIR / EN | D54 (A0) / D55 (A1) / D38 | RAMPS **X** socket (driver plugs in) | Marlin `pins_RAMPS.h` X_STEP/DIR/ENABLE; KiCad port nets `/X-STEP` etc. |
| Dial B STEP / DIR / EN | D60 (A6) / D61 (A7) / D56 (A2) | RAMPS **Y** socket | Marlin Y_*; KiCad `/Y-*` |
| Dial C STEP / DIR / EN | D46 / D48 / D62 (A8) | RAMPS **Z** socket | Marlin Z_*; KiCad `/Z-*` |
| Dial A DIAG | D3 (INT, `attachInterrupt` no. 1) | **X_MIN** header, S pin | Marlin X_MIN_PIN 3 |
| Dial B DIAG | D2 (INT, no. 0) | **X_MAX** header, S pin | Marlin X_MAX_PIN 2 — *moved from Y_MIN* |
| Dial C DIAG | D18 (INT, no. 5) | **Z_MIN** header, S pin | Marlin Z_MIN_PIN 18 |
| Key STEP / DIR / EN | D26 / D28 / D24 | RAMPS **E0** socket (driver plugs in) | Marlin E0_STEP/DIR/ENABLE (`pins_RAMPS.h`) — *rev 2026-10-08.1* |
| Key DIAG | D19 (INT, no. 4) | **Z_MAX** header, S pin (F–F jumper from the top of the E0 driver's DIAG pin) | Marlin Z_MAX_PIN 19 |
| UART TX2 | D16 | **AUX-4 pin 18** ← pigtail lead TX2 (R1 1 kΩ in line) | Marlin: "Serial2 — TX2 = D16 RX2 = D17 (AUX4-18 and AUX4-17)" |
| UART RX2 | D17 | **AUX-4 pin 17** ← pigtail lead RX2 (to the splice) | same |
| Drivers' PDN_UART | — | top of the **RX pin** of the drivers in X, Y, Z **and E0** ← pigtail leads A, B, C, KEY | BTT V1.3 schematic: RX = `UART_RX` = PDN_UART |
| Start / stop button | D14 (input, pull-up) | **Y_MIN** header: S and − pins | Marlin Y_MIN_PIN 14 (no interrupt needed) |
| Spare (was 5 V/GND for the remote board until rev 2026-10-08.1) | 5 V, GND | Y_MAX header + and − pins | KiCad: endstop pin 3 = 5 V, pin 2 = GND |
| Status LED | D13 | on-board LED | Marlin LED_PIN 13 |
| Spare | D15 | Y_MAX header, S pin | — |
| Spare (key STEP until rev 2026-10-08.1) | D23 | AUX-4 pin 16 | — |
| USB serial (log) | D0 / D1 | USB | keep free |

Pins to avoid: D0/D1 (USB). D20/D21 carry 4.7 kΩ pull-ups to 5 V on RAMPS
(KiCad R21/R22). Using D14/D15 and D18/D19 as plain I/O means `Serial3` and
`Serial1` can't be used — the firmware doesn't need them.

Interrupt numbers are from the Arduino AVR core's `digitalPinToInterrupt()` for
the Mega (`variants/mega/pins_arduino.h`): only D2, D3 and D18–D21 have one.

RAMPS endstop headers are 3 pins: **S** (signal), **−** (GND), **+** (5 V)
(KiCad port: pad 1 = signal, 2 = GND, 3 = VCC). RAMPS has no pull-up or filter
on these lines; the firmware uses the Mega's internal pull-up, so an unplugged
DIAG wire reads *high* = "stalled" and the firmware refuses to move (fail safe).

## 2. Drivers on RAMPS: placement, jumpers, UART tap

| RAMPS socket | Dial | MS1 jumper | MS2 jumper | MS3 jumper | UART address |
|---|---|---|---|---|---|
| X | A (top-left) | off | off | **off** | 0 |
| Y | B (top-right) | **on** | off | **off** | 1 |
| Z | C (bottom) | off | **on** | **off** | 2 |
| **E0** | **key** | **on** | **on** | **off** | **3** |
| E1 | empty | — | — | — | — |

- **E0 (rev 2026-10-08.1) — VERIFY on the bench**: E0's MS jumpers and MS3
  jumper pin are wired like X/Y/Z's (the netlist reading above covers every
  socket; E0 itself is confirmed only when the key driver answers `ping` at
  address 3 with MS1 = MS2 = 1).
- Address table: TMC2209 DS §3.4 "MS1/MS2" (p. 14): MS2,MS1 = GND,GND → 0;
  GND,VCC_IO → 1; VCC_IO,GND → 2; VCC_IO,VCC_IO → 3. MS1/MS2 have internal
  pull-downs (DS §2.2, "DI (pd)", p. 9); RAMPS adds 100 kΩ on MS1 (KiCad
  R3/R5/R6/R8/R10). A RAMPS jumper ties its pin to 5 V (KiCad: jumper pads
  2/4/6 = VCC, pads 1/3/5 = MS1/MS2/MS3 of the socket).
- **Driver orientation**: match the driver's EN, DIR, VM and GND corner pins to
  the RAMPS silkscreen. A reversed driver is destroyed (BTT manual,
  "Safety Precautions" 1).
- **UART tap**: the V1.3's header pins in the StepStick order are EN, MS1, MS2,
  **RX**, TX, CLK, STEP, DIR (BTT manual p. 5). Its schematic shows **RX =
  PDN_UART** (net `UART_RX`, chip pin 14) and **TX** connected to it only
  through **R10, which is not fitted** (marked NC). **Measured (Paul,
  2026-10-08):** RX to TX is open on his drivers (no continuity), so R10 is
  open as the schematic says. Paul's drivers have the RX, TX and CLK pins
  standing up through the top (tall pins; all five alike, Paul 2026-10-08),
  and a female Dupont on the top of RX grips and conducts (Paul checked
  continuity pin → far end of the lead). **The tap is the top of the RX
  pin** (revision 2026-10-08.2). Put nothing on TX or CLK.
- On the RAMPS, the RX pin also goes into the socket's MS3 hole, which leads
  only to that socket's MS3 jumper pad (KiCad net `U2.MS3 ↔ JP1.5`; each
  socket's MS3 is its own net, checked for all five sockets 2026-10-08, so
  the unused E1 block can't be used as a tap). With the MS3 jumper off,
  nothing else is on the line. *Until revision 2026-10-08.2* the tap was that
  MS3 jumper pin, under the seated driver.
- **Don't bridge R10 on any driver**: RAMPS ties the socket's RST and SLP
  pins together (KiCad net `U2.SLP ↔ U2.RST`), which on the V1.3 are TX and
  CLK. With R10 open, CLK sees only its 20 kΩ pull-down (BTT schematic R4) →
  internal clock, as the datasheet wants ("Tie to GND … for internal clock",
  DS §2.2). With R10 bridged, PDN_UART would be wired to CLK.
- RAMPS has a **10 kΩ pull-up on every EN line** (KiCad R16–R20), so the dial
  drivers stay disabled until the firmware drives EN low.

## 3. The open harness issues, resolved

### 3.1 Conductor count — retired (revision 2026-10-08.1)

This section chose which six signals the inter-unit cable carried to a remote
key driver (EN and DIR tied low there, direction by GCONF.shaft). With the
key driver on the RAMPS (E0) there is no such cable: only the key motor's own
cable runs between the units (section 4). The old text is in git history
(`main` at `76a4167`).

### 3.2 UART resistor topology

**Choice: one 1 kΩ in total, between TX2 and the bus; RX2 on the bus; all four
PDN_UART pins on the bus.** DS §4.3 Fig. 4.1 (p. 20) shows exactly this: master
TXD → 1 kΩ → line; RXD and every node's PDN_UART on the line; addresses by
MS1/MS2. The 1 kΩ lets a driver pull the line while TX2 idles high.
Consequences:

- The Mega receives its own transmissions (DS §4.4, p. 21: "all transmitted
  data also is received by the RXD input"). TMCStepper handles this: its read
  skips bytes until it sees the reply header `0x05 0xFF <reg>` (replies use
  master address 0xFF, DS p. 19) — `TMC2208Stepper::_sendDatagram()`, v0.7.3.
- Multi-node: set **SENDDELAY ≥ 2** on every driver (DS p. 19: "In a
  multi-node system, set SENDDELAY to min. 2 for all nodes"). The firmware does.
- Baud: 115200 (valid range 9000 baud to fCLK/16 = 750 k, DS p. 18).
- `sequence.md`'s "one resistor per driver" is corrected in place.

### 3.3 BTT TMC2209 V1.3 pin access on RAMPS

- **UART**: no soldering. A pigtail lead (section 5) clips onto the top of the
  driver's **RX** pin (section 2).
- **DIAG**: the V1.3 has extra pins at the EN end (BTT schematic header P1B
  lists INDEX, DIAG and VREF). On Paul's drivers (photos, 2026-10-08) the top
  edge reads, from the EN corner: the EN pin, a short unlabelled pin, an
  empty hole, then the pin with **"DIAG"** printed under it, next to the
  trimmer pot. Both fitted pins stick out **above and below** the board (Paul,
  all five drivers). BTT's manual shows them pointing down only ("BOTTOM
  (Factory default)", p. 6); Paul's are through-pins. **For all four drivers
  (X, Y, Z, E0), before fitting the heatsinks:**
  1. With flush cutters, cut the **bottom** ends of both EN-end pins off flush
     with the underside (or their plastic spacer). Seated, they would point
     down between the socket rows at the EN end. The RAMPS KiCad puts the MS
     jumper block toward the DIR end, so they're probably clear, but what's
     under them on Paul's Fasizi board isn't checked; cutting removes the
     question. Leave the top ends.
  2. A plain F–F jumper (~10 cm) from the **top of the DIAG pin** (the one
     next to the trimmer pot) to the S pin of that driver's endstop header
     (section 1): X_MIN (A), X_MAX (B), Z_MIN (C), Z_MAX (key).
  Put nothing on the other EN-end pin. *Until revision 2026-10-08.2* this was
  a soldered lead on the DIAG joint (the docs assumed down-only pins).
- **VERIFY**: which pin is DIAG. The firmware's `ping` prints the DIAG state
  both from the Mega pin and from the driver's own IOIN register; bench stage
  3 stalls the motor by hand and both must flip together.

### 3.4 Address strapping

Section 2 table. The firmware reads each driver's IOIN (MS1, MS2 bits and
VERSION, which must read 0x21 — DS IOIN, p. 25) and refuses to run if any
address doesn't answer or reports the wrong MS1/MS2.

### 3.5 Power and 5 V logic for the remote driver — retired (revision 2026-10-08.1)

The key driver now sits in E0 and gets VS (12 V, through RAMPS's 5 A
polyfuse: KiCad input terminal pin 3 → F1 MF-R500 → `+12V` → all socket VMOT
pins) and VIO (the RAMPS 5 V rail) from its socket, like the dial drivers,
with RAMPS's own 100 µF near the sockets. The remote board's 5 V-over-cable
and its two 100 µF capacitors (C1a, C1b) are gone. DS §3 (p. 11): "A minimum
capacity of 100µF near the driver is recommended"; the V1.3 itself only has
2 × 10 µF ceramic (BTT schematic C1/C2).

### 3.6 Mount for the remote board — retired (revision 2026-10-08.1)

No remote board, so no mount on the key turner.

## 4. Key motor cable (revision 2026-10-08.1)

The only connection between the units. The key motor's own cable (supplied
with the 17HE19-2004S, ~1 m, 4 wires and a connector) runs from the key
turner to the RAMPS **E0 motor header**, the same kind of 4-pin header the
dial motors plug into.

- **Length (Paul, 2026-10-08):** use the supplied cable as it is. If bench
  stage 5 shows the key's StallGuard reading too dull to tell the stop
  apart, shorten it. Standard practice (3D printers home with StallGuard on
  mainboard drivers over cables of this length) suggests 1 m is fine; not
  yet confirmed on this hardware.
- **Strain relief**: zip-tie it to the key turner within ~20 mm of the motor
  and to the electronics deck near the RAMPS, so a tug lands on the ties.
  Coil the spare length; keep it clear of the key cap's rotation.
- **Never plug or unplug it with 12 V on**: DS §3 "Attention" (p. 11) —
  energy from the motor coils goes back into the supply when a driver gets
  cut off from its motor.
- **Wire order**: as for the dial motors (`docs/manual.md` §2.9): on some
  17HE19-2004S the two middle wires are swapped. Symptom: the
  motor buzzes or jitters instead of turning. Fix it in the connector.
- *Until revision 2026-10-08.1* this section described a 6-conductor
  shielded cable with Phoenix 8-pin connectors to a remote driver board; see
  git history (`76a4167`).

## 5. UART pigtail — the UART junction (revision 2026-10-08.2)

The bus node and R1 are built into a small harness instead of a board
(Paul, 2026-10-08): six leads, each ending in a female Dupont, joined in one
solder splice. Drawing: `control/harness/uart_pigtail.svg`. Build steps:
`docs/manual.md` §2.5.

| Lead (tape label) | Female end goes on | Other end |
|---|---|---|
| **TX2** — R1 1 kΩ in line, ~3 cm from the female end | AUX-4 pin 18 (D16) | R1 → splice |
| **RX2** | AUX-4 pin 17 (D17) | splice |
| **A** | top of the RX pin, driver in X (dial A, addr 0) | splice |
| **B** | top of the RX pin, driver in Y (dial B, addr 1) | splice |
| **C** | top of the RX pin, driver in Z (dial C, addr 2) | splice |
| **KEY** | top of the RX pin, driver in E0 (key, addr 3) | splice |

- **The splice is the bus node** of DS Fig. 4.1: R1's far end, RX2 and the
  four PDN_UART leads. Heat shrink over the joint and over R1; zip-tie the
  splice to the deck so the leads can't pull on it.
- **Leads**: six F–F jumpers with one end cut off each (or jumper halves if
  long enough), cut to the measured run from AUX-4 / each driver's RX pin to a
  splice near the middle of the RAMPS, plus a few cm.
- **Signals only**: no 12 V, 5 V or GND. The Mega and all four drivers share
  ground through the RAMPS.
- **Check before fitting** (multimeter, Ω): TX2 → RX2 ≈ 1 kΩ; TX2 → A, B, C,
  KEY ≈ 1 kΩ each; RX2 → A, B, C, KEY ≈ 0 Ω each.
- Each driver lead keeps its own female end, so a driver can still be
  unplugged (pull the lead off its RX pin first).

*Until revision 2026-10-08.2* this was a perfboard ("hub board") with male
pins for six F–F jumpers: the same circuit and the same six jumpers, but six
more plug-in joints (one at each hub pin) and a part to mount.
Before revision 2026-10-08.1 it also split 12 V to a fused key branch.

## 6. Remote driver board (key turner) — retired (revision 2026-10-08.1)

The key driver plugs into the RAMPS E0 socket instead (section 2). The
remote board's layout (6.1) and mount needs (6.2) are in git history
(`main` at `76a4167`).

## 7. Motor current settings

Sense resistors on the V1.3: **0.11 Ω** (BTT schematic R3/R5 "0R11"; visible as
"R110" on the board, manual p. 6). Current set by UART with the internal
reference (GCONF.I_scale_analog = 0), so the module's VREF pot doesn't matter
once the firmware is running. **Correction (2026-10-07):** it does after a
driver reset (its supply dipping), until the firmware notices: so every
driver's pot goes to minimum (decision log, 2026-10-07).
RMS current = (CS+1)/32 × VFS/(R_SENSE + 20 mΩ)/√2,
VFS = 0.325 V (vsense = 0) or 0.18 V (vsense = 1) (DS §9, p. 53). TMCStepper's
`rms_current()` implements this and switches vsense when CS would be < 16; the
datasheet asks for IRUN 8…31 in StealthChop (p. 42).

| Driver | Run (IRUN) | Hold (IHOLD) | Why |
|---|---|---|---|
| Dial A, B, C | **1.0 A RMS** (CS 17 → 0.99 A) | 0.5 A | `sequence.md`: ~1 A until dial torque is measured; the 2:1 gearing doubles what reaches the printed teeth |
| Key | **0.6 A RMS to start** (vsense=1, CS 18 → 0.58 A) | 0.3 A | measured key torque 0.07–0.08 N·m; want ~2×. Bench stage 5 finds the lowest current that still turns the key through its free travel; set 2 × that (torque ∝ current), max 1.0 A |
| Ceiling (firmware clamps) | 1.2 A | — | DS: 1.4 A RMS design guideline (p. 75); BTT: active cooling above 1.2 A |

**ASSUMPTION**: the motor's "2.0 A" rating is RMS per phase. Not confirmed
(vendor site unreachable from here); it only matters if we ever go above 1 A.

StealthChop (SPREAD open = StealthChop, DS §3.4; firmware also clears
GCONF.en_spreadCycle) — StallGuard4 only works in StealthChop (DS §11).

## 8. Power-up and power-down order, fusing

1. **All connections with power off** (USB unplugged, 12 V off).
2. **Every driver's VREF pot to minimum before any motor is connected**
   (decision log, 2026-10-07: a driver that resets runs on its pot until the
   firmware notices). **Correction (2026-10-09):** this used to say "before
   the first power-up", but the pot is fed from the driver's own 5VOUT (BTT
   V1.3 schematic: R8 from 5VOUT, pot R9, wiper → R11 → VREF), so it only
   reads with 12 V on, and BTT's manual doesn't say which way is minimum. It
   is set by measurement in bring-up stage 1 (step 3a): 12 V on, driver off
   (EN pull-up), no motor. *Revision 2026-10-08.1*: every driver, the key's
   included, now has its EN on a Mega pin with RAMPS's 10 kΩ pull-up, so all
   four stay off at power-up until the firmware enables them. (Before, the
   remote key driver's EN was tied low and it came on with 12 V, DS p. 52
   warning.)
   Expect the key to twitch by up to ±2 full steps (±3.6°) when the motor is
   first energised (DS p. 15: the motor pulls into the driver's step position
   at power-up).
3. **Power-up**: USB first (Mega + every driver's VIO), then 12 V. The firmware
   pings all 4 drivers and won't move anything until all answer — so it just
   waits for 12 V. (RAMPS also feeds 12 V to the Mega's VIN through a diode,
   KiCad D1, so the Mega runs without USB too. **The Mega's own barrel jack
   stays empty.** It feeds only VIN, and D1 conducts only from the RAMPS
   +12 V rail to VIN, so a supply there would never reach the drivers'
   VMOT (netlist: `/AM-VIN` = U1.VIN + D1 cathode only). USB first is so the logger sees
   the start.)
4. **Power-down**: 12 V off first, then USB.
5. **Fusing**: PSU (Ledmo HTY-1200500) 5 A max. RAMPS 5 A polyfuse (F1)
   feeds all four drivers (revision 2026-10-08.1). Four motors at their set
   currents stay well inside it: a stepper driver's supply current is below
   its coil current (chopper). *Until revision 2026-10-08.1* a 1.1 A PTC (for
   a while a 1.6 A glass fuse in a printed holder) on the hub fed a separate
   key branch; it went with the branch.
6. **Emergency stop**: pull the 12 V plug. The button (Y_MIN) pauses a run;
   `!` on the serial line aborts the current move and switches all drivers
   off.

## 9. Diagrams

- **`control/harness/schematic.pdf`: the full wiring schematic**, A4
  landscape sheets in colour, for printing. No text is below 8 pt. It is
  drawn from this file by `control/harness/schematic.py` (reportlab), and
  prints the project revision (`REVISION`) in every title block.
  **Regenerate it after any change here.**
- `control/harness/harness.yml` → `harness.svg` / `harness.png` (WireViz):
  the UART pigtail between the RAMPS pins and its splice, and the key motor
  cable to E0.
- `control/harness/overview.dot` → `overview.svg` (Graphviz): block diagram
  of everything in this file.
- `control/harness/uart_pigtail.py` → `uart_pigtail.svg` / `.png`: the
  UART pigtail (revision 2026-10-08.2; replaced `hub_board.py`).
- `control/harness/ramps_and_uart.md`: one bench sheet of everything fitted
  to the RAMPS, and the pigtail (was `ramps_and_hub.md`).

Regenerate: `python3 control/harness/schematic.py` (needs `pip install
reportlab`), `wireviz control/harness/harness.yml`,
`dot -Tsvg control/harness/overview.dot -o control/harness/overview.svg` and
`python3 control/harness/uart_pigtail.py`. Then `python3 tools/check_revision.py`.

## 10. Shopping list (beyond `docs/bom.md`'s "still to buy")

Every discrete part, with what's ordered and what's already on the RAMPS
or the driver modules: `docs/bom.md`, "Electronics assembly — every
discrete part" (2026-10-07).

| Item | Qty | For |
|---|---|---|
| **Multimeter** — **on hand** (Paul, 2026-10-07) | 1 | 12 V polarity at the DC-jack adapter before first power-up |
| F–F Dupont jumpers, 10–20 cm — **ordered** 2026-10-07 | ~20 | UART pigtail (6 leads, one end cut off each), DIAG leads (4 plain jumpers, rev 2026-10-08.2), the button |
| Heat shrink — **ordered** | — | over R1 and the pigtail splice |
| Female DC barrel jack **5.5 × 2.1 mm** → screw terminal adapter (fits the Ledmo HTY-1200500 plug, centre positive) — **ordered** 2026-10-07 | 1 | PSU → RAMPS "5A" terminal without cutting the plug. Check its + / − marking with the multimeter before first use |
| 20 AWG wire, red + black, ~1 m each — **ordered** 2026-10-07 | 1 | adapter → RAMPS 12 V |
| Solder — **on hand**: came with the station, with wick (Paul, 2026-10-07) | — | |
| Flush cutters — **on hand** (Paul, 2026-10-07) | 1 | DIAG pin mod |

**No longer needed from revision 2026-10-08.1** (bought; keep as spares):
the 1.1 A PTC fuses and the 5 × 20 mm fuse kit + printed holder (no separate
key branch), the 100 µF capacitors (no remote board), the 6-conductor
QUARKZMAN cable and the Phoenix 8-pin connectors (no inter-unit signal
cable), the female header strips (no driver socket on a perfboard).
**And from revision 2026-10-08.2:** the perfboard and the male header strip
for the hub board (the UART pigtail replaces it).

## 11. Things to verify on the bench (steps in `control/bringup.md`)

- UART pigtail: the multimeter readings in section 5 before fitting.
- **Done (Paul, 2026-10-08):** a female Dupont grips the top of the RX pin and
  conducts; RX–TX open (R10 not fitted); all five drivers alike, EN-end pins
  through the board. (This replaces the old "Dupont under the driver on the
  MS3 jumper pin" check.)
- UART: every driver answers `ping` with its lead on RX (stage 1).
- Which EN-end pin is DIAG: silkscreen says the one next to the pot; stage 3
  confirms it (`ping` + a hand stall).
- The E0 socket: the key driver answers `ping` at address 3 (MS1 = MS2 = 1).
- The key's StallGuard through the 1 m motor cable (stage 5); shorten the
  cable if it reads too dull (Paul, 2026-10-08).
- ~~Motor step angle 1.8°~~ confirmed in bring-up stage 2 (Paul, 2026-10-10).
- Motor direction vs dial numbering and vs key clockwise (firmware config).

## Sources

1. **Marlin** `Marlin/src/pins/ramps/pins_RAMPS.h`, bugfix-2.1.x at
   [`bbe7c65`](https://github.com/MarlinFirmware/Marlin/blob/bbe7c65573672d8efe49d7777e3ae221f38b6b55/Marlin/src/pins/ramps/pins_RAMPS.h)
   (2026-10-04): stepper, endstop and AUX-1…4 pin numbers; Serial2 on
   AUX4-17/18. E0_STEP 26, E0_DIR 28, E0_ENABLE 24 re-read from
   bugfix-2.1.x on 2026-10-08 (rev 2026-10-08.1).
2. **TMC2209 datasheet** rev 1.09 (2023-02-16), Trinamic/ADI. analog.com is
   blocked from this session; read from the copy in
   [janelia-arduino/TMC2209 `d9f138d`](https://github.com/janelia-arduino/TMC2209/blob/d9f138d049a51c2300d557b47bb5f4dfea4e9b29/datasheet/TMC2209_datasheet_rev1.09.pdf).
   Page numbers above are that PDF's.
3. **BIGTREETECH TMC2209 V1.3** user manual v1.00 (2024-01-26), schematic
   `TMC2209 V1.3-SCH.pdf`, size drawing `TMC2209 V1.3-SIZE.pdf` —
   [bigtreetech/BIGTREETECH-Stepper-Motor-Driver `9f96800`](https://github.com/bigtreetech/BIGTREETECH-Stepper-Motor-Driver/tree/9f9680040e7f696f132b1c0d75a6f79c9f288b13/TMC2209/V1.3).
4. **RAMPS 1.4 netlist**: the KiCad port
   [matt3u/RAMPS-1.4_KiCad `ea33bdf`](https://github.com/matt3u/RAMPS-1.4_KiCad/blob/ea33bdf253b7a8aa695ff820b05b6ff0bcea4b7c/RAMPS_1-41.kicad_pcb)
   — nets read pad by pad from the `.kicad_pcb`. The original Eagle files on
   reprap.org were unreachable from here. Paul's board is a Fasizi clone; the
   things that matter (UART pin, DIAG, addresses) are checked by the firmware
   on the bench.
5. **TMCStepper** 0.7.3, [teemuatlut/TMCStepper](https://github.com/teemuatlut/TMCStepper/tree/v0.7.3):
   `TMC2208Stepper::read()` / `_sendDatagram()` (echo handling, CRC, retries),
   `rms_current()`.
6. **Arduino AVR core** 1.8.6, `variants/mega/pins_arduino.h`
   (`digitalPinToInterrupt`).
7. Motor: STEPPERONLINE 17HE19-2004S (see `docs/housing_decisions.md`,
   2026-10-03). Step angle 1.8° confirmed on the bench (bring-up stage 2, Paul,
   2026-10-10).

## Decision log (most recent first)

### 2026-10-08 (evening) — UART on the driver's RX pin; DIAG without soldering (revision 2026-10-08.2)

**What Paul found on his drivers** (BTT TMC2209 V1.3, all five alike; photos
and bench checks, 2026-10-08):
- The **RX, TX and CLK** pins stand up through the top of the board as tall
  pins. BTT's pinout card labels RX and TX both "PDN"; the V1.3 schematic has
  RX = `UART_RX` = the chip's PDN_UART (pin 14), and TX joins it only through
  R10 (NC). **RX–TX measured open** on Paul's driver, so R10 is open.
- A female Dupont on the top of RX grips well and conducts (continuity from
  the pin to the far end of the lead).
- The two EN-end pins go **through** the board (above and below). The
  silkscreen prints "DIAG" under the one next to the trimmer pot; between it
  and the other fitted pin is an empty hole. BTT's manual photo shows them
  pointing down only, which is what the old DIAG mod assumed.
- Also checked (RAMPS 1.4 KiCad, 2026-10-08): each socket's MS3 is its own
  net (socket MS3 ↔ its jumper pad 5 only). Paul's idea of tapping the
  unused E1 block wouldn't reach any driver.

**Decision:**
- **UART tap = top of each driver's RX pin.** It avoids the RAMPS MS3 jumper
  pin under a seated driver, whose clearance was never checked, and needs no
  soldering. Electrically identical (RX is the pin in the socket's MS3 hole).
  The MS3 jumper stays off.
- **DIAG = plain F–F jumper on the top of the DIAG pin.** Still cut the
  bottom ends of both EN-end pins: seated, they'd point down between the
  socket rows, and what's under them on Paul's board isn't checked.
- Leave TX, CLK and the other EN-end pin free. Don't bridge R10.

**Correction** to the pigtail entry below: its "move the lead to the other
MS3 pin" fallback no longer applies; the lead goes on RX, which has been
checked.

### 2026-10-08 — hub board → UART pigtail (revision 2026-10-08.2)

**Paul:** with only a resistor and a junction left, the hub "feels more like a
custom cable than a full daughter board".

**Agreed.** After revision 2026-10-08.1 the hub held only R1 and the bus node
(section 5's old table): one resistor and a six-way junction, all signals.
A harness does the same with less:
- no part to mount on the deck (that mount was still an open CAD item), and
  the area over the drivers stays clear for cooling and bring-up access
  (Paul had considered stacking a perfboard over the RAMPS on its three
  holes; the heatsinks' height and airflow would have had to be checked);
- six fewer plug-in joints: the same six jumpers, but their hub ends are
  now one solder splice instead of six Dupont-on-pin contacts;
- nothing lost for debugging: every lead keeps its own female end, so the
  "move the lead to the other MS3 pin" fallback in stage 1 still works.

**Same circuit** as DS Fig. 4.1: TX2 → 1 kΩ → bus; RX2 and every PDN_UART on
the bus. R1 now sits ~3 cm from the TX2 female end instead of "right at the
TX2 pin" on the board. **Assumption** (not from a source): at 115200 baud
and these lead lengths (tens of cm), where R1 sits along the TX2 lead makes
no difference; the old "right at the pin" note was neatness, not a
datasheet requirement. If stage 1 shows UART errors, this is one thing to
look at.

**Changed:** section 5 rewritten; pin map rows for TX2/RX2/PDN; diagrams
(`uart_pigtail.svg` replaces `hub_board.svg`; schematic sheets 1, 2, 5, 6, 7;
harness; overview); `ramps_and_hub.md` renamed `ramps_and_uart.md`. Also
fixed on schematic sheet 1: the 12 V line was drawn into the hub block
instead of the RAMPS (**Correction**: it was wrong in revision 2026-10-08.1
too; 12 V has gone to the RAMPS "5A" terminal since then).

### 2026-10-08 — key driver onto the RAMPS, E0 socket (revision 2026-10-08.1)

**Paul's question:** couldn't the key driver go on the existing board, with
just the motor cable running to the key turner?

**Why it was remote:** `control/sequence.md` (2026-09-29) put each driver
next to its motor because "StallGuard reads back-EMF right at the motor, and
long motor-phase wiring would dull that sensitivity". **No source supports
that.** StallGuard is measured inside the driver, from the coil current
regulation; and the usual practice contradicts it: 3D printers do
sensorless (StallGuard) homing with TMC2209s on the mainboard and the motors
at the end of their cables (Klipper's TMC driver documentation describes it
for exactly that layout). The key motor comes with ~1 m of cable, and the key
turner is ~125 mm from the dial unit. *Correction*: the premise is withdrawn,
in `sequence.md` too.

**Decision: the key driver goes in the RAMPS E0 socket** (empty until now).
- It gets STEP / DIR / EN from E0 (D26 / D28 / D24, Marlin `pins_RAMPS.h`),
  so the UART workarounds go: EN no longer tied low (TOFF disable),
  DIR no longer tied low (GCONF.shaft read back before every key move).
- VS and VIO come from the socket, through RAMPS's 5 A polyfuse and its own
  100 µF capacitors, like the dials. That removes the supply path whose dips
  could reset the key driver (fuse-holder contacts, PTC, the cable): the
  case firmware v0.3's GSTAT check was written for. The check stays: a
  driver can still reset.
- Address 3 by the MS1 + MS2 jumpers under E0, like the others.
- The key motor's own cable plugs into the E0 motor header. Paul will use it
  as supplied and shorten it if the key's StallGuard reads too dull (bench
  stage 5).

**What it costs:** a fourth DIAG mod; four motor wires between the units
instead of six signals; firmware v0.4 (key pins; DIR/EN like the dials).

**What goes:** the remote driver board (section 6) and its mount on the key
turner (a CAD to-do, now closed), the 6-conductor cable and Phoenix
connectors (section 4), the hub's 12 V branch, fuse and Phoenix header
(section 5), the two 100 µF (C1a, C1b). The interim fuse holder
(`cad/fuse_holder.scad`) printed well (Paul) but has no job now.

**Not verified:** anything on hardware. E0's MS3/MS jumpers are assumed
wired like X/Y/Z's (bench `ping` at address 3 confirms); the key's StallGuard
through 1 m of cable is confirmed in stage 5.

### 2026-10-07 — every driver's VREF pot to minimum (firmware v0.3)

- Firmware v0.3 reads each driver's GSTAT before and after every move and
  stops on a reset (`control/firmware/README.md`, "Driver resets").
- A reset *during* a move is seen only when the move ends. Until then, the
  driver runs on its power-on registers. That means `I_scale_analog` = 1,
  so the current is set by the VREF pot, with `IRUN` = 31 (DS pp. 23, 28).
- The longest moves are the dials' homing passes, up to 1.15 dial turns
  into the stop. A dial pressed there at an unknown pot current is the kind
  of force the relocker research says to avoid (`control/lock_research.md`).
- So every pot goes to minimum, not just the key's (§8). There's no
  downside: the firmware always selects the internal reference, and it
  holds the dial drivers disabled (EN high) from its start until it has
  set them up.
- **Paul agreed (2026-10-07).** `docs/manual.md` 2.3, step 4; §8, step 2;
  schematic sheet 7.

### 2026-10-07 — interim fuse for hub F1 (Paul)

- The PTC fuses are ordered, but no amazon.fr listing arrives soon
  (the first pick: 31 Oct – 5 Nov). Paul ordered **1.6 A glass cartridge
  fuses** to sit in F1's place until then, in a holder he prints (no clips
  ordered): an AUKENIEN kit, **T (slow-blow), 5 × 20 mm, 250 V**, 10 of
  each of 12 values from 0.5 to 10 A. Slow-blow is the right kind here,
  because the power-on charging surge into C1a/C1b is brief.
- **Why 1.6 A works:** the key branch draws less than 0.6 A (§8, item 5),
  and 1.6 A is well below the 5 A the PSU can deliver into a short. A
  short on the cable, the plug or the remote board blows the fuse instead
  of drawing the PSU's full current.
- **Not resettable:** a blown fuse means a real fault. Find it with the
  multimeter before fitting a new one.
- **What leaving F1 out would have meant:** a fault in the key branch
  gets the PSU's full current until the plug is pulled. That's the same
  protection the dial drivers already have: the RAMPS polyfuse holds 5 A,
  so on a 5 A supply it's effectively the supply's own limit. Whether
  the Ledmo shuts down on a short is not known (no data sheet).
- **The holder's contacts must be solid.** A contact that drops out for a
  moment cuts the key driver's VS, and its logic runs from VS (§3.5), so
  it resets to its power-on registers. The firmware writes the driver's
  setup once per session and doesn't check for a reset before a key
  move, so a reset would go unnoticed (follow-up for the firmware).
  **Update 2026-10-07: done in firmware v0.3.** It reads each driver's
  GSTAT around every move and before every attempt, and stops with
  `DRVFAULT` on a reset (`control/firmware/README.md`, "Driver resets").
  Solid contacts still matter: each dropout now stops the run.
  Metal-to-metal contact on each end cap, held by spring pressure or by
  a screw threading into a metal nut, not into the plastic: PETG and PLA
  creep under steady load, so a clamp that bears only on plastic
  loosens. Don't solder to the end caps: the heat can melt the solder
  that holds the fuse wire inside.
- **C1 as ordered isn't sold as low ESR** (now C1a + C1b, below). It's an Innfeeltech
  100 µF 35 V radial, 50 pcs; the listing gives no ESR, ripple-current or
  temperature rating. TMC2209 DS §3 recommends low-ESR electrolytics, with
  at least 100 µF near the driver (§3.5).
  - **Likely fine at the key's current** (0.6 A to start, ≤ 1.0 A),
    because the V1.3 module's own 2 × 10 µF ceramics sit right at the
    chip. This is a judgement, not a measurement: the cap's ESR is
    unknown.
  - **Decided (Paul, 2026-10-07): two in parallel**, C1a and C1b. That
    gives 200 µF at half the ESR of one, and there are 50 in the pack.
    The ~70 × 30 mm remote board has room beside VM/GND (§6.1).
  - **Bench check at stage 5:** after a few minutes of key moves at the
    final current, touch C1a and C1b. They should feel cool. If it's noticeably
    warm, order a low-ESR part (`docs/order_remaining_parts.md`).

### 2026-10-07 — printable schematic

- Added `control/harness/schematic.pdf` and its generator. Nothing in the
  wiring changed.
- RAMPS parts it shows, checked in the RAMPS 1.4 KiCad netlist (Sources,
  item 4):
  - the power input terminal is **X4**. Its '5A' pair: pin 3 goes through
    **F1 (MF-R500)** to the `+12V` net; pins 2 and 4 are GND. Its '11A' pair
    feeds the heated-bed outputs through **F2**, and is not used here;
  - on `+12V` sit every socket's VMOT, the 100 µF capacitors **C3, C4, C6,
    C7, C9, C10**, and the anode of **D1 (1N4004)**;
  - D1's cathode goes to the Mega's VIN.

  So the RAMPS F1 protects the three dial drivers and the Mega's VIN feed.
  That confirms §3.5 and §8.
- Not new: the schematic labels interrupt pins "(irq)". The numbers in §1
  ("attachInterrupt no. 1", …) are Arduino interrupt numbers, not the
  ATmega2560's INTn pin names: D2 is INT4, D3 is INT5, D18 is INT3 and D19
  is INT2.

### 2026-10-06 (evening) — PSU plug and cable colours, from Paul

- PSU: **Ledmo HTY-1200500**, 5.5 × 2.1 mm barrel, centre positive. The
  shopping list now names a 5.5 × 2.1 DC-jack-to-screw-terminal adapter
  (§5, §10).
- Cable colours: red, green, black, white, orange, yellow. Assigned in §4:
  red 12 V, black GND, orange 5 V, yellow STEP, green UART, white DIAG.
  The WireViz harness has been re-rendered with these colours.

### 2026-10-06 — harness v1 (this file)

- Settled CLAUDE.md harness issues 1–6 as above.
- **Correction** to `control/sequence.md` (2026-09-29 wiring plan): "a ~1 kΩ
  resistor between the MCU's UART TX pin and its own PDN_UART pin … one
  resistor per driver" is wrong for a shared bus. The datasheet's circuit has
  one 1 kΩ between TX and RX/the bus (Fig. 4.1).
- **Correction**: dial B's DIAG moves from Y_MIN (D14) to X_MAX (D2): DIAG is
  a pulse (DS §11.2, p. 59), the firmware latches it in an interrupt, and D14
  has no external interrupt in the Arduino core. Y_MIN takes the button.
- **Change**: the key-turner driver uses STEP + DIAG + UART only; DIR and EN
  are tied low on its board (was "STEP/DIR/EN + DIAG").
- New: hub board at the dial end; remote 12 V branch fused at 1.1 A.

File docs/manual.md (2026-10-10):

# Fichet safe robot — build and operating manual

> **Revision 2026-10-09.1** · key driver on the RAMPS E0 socket; UART pigtail replaces the hub board · log: `docs/revisions.md`

For Paul. Covers the robot as of **revision 2026-10-08.2**: dial unit v2, key
turner v1, wiring with all four drivers on the RAMPS and the UART pigtail
(`control/wiring.md`), firmware **0.4** (unchanged by 2026-10-08.2).

**Status:** nothing has run on hardware yet. The first time through, follow
the bench bring-up (`control/bringup.md`) instead of section 5. It builds
and tests the electronics one stage at a time, and its results fill in the
values that `config.h` still guesses. Every step here that rests on an
unchecked fact says **VERIFY** or **ASSUMPTION**.

**This manual is the procedure; the detailed docs are the reference.** If
the two ever disagree, the reference wins. Tell me, and I'll fix the
manual:

| Topic | Reference |
|---|---|
| Housings, print and fit history | `docs/housing_decisions.md` |
| Parts and orders | `docs/bom.md` |
| Wiring, pin map, currents, power order | `control/wiring.md` |
| Firmware commands and log lines | `control/firmware/README.md` |
| Values not yet measured | `control/firmware/safe_robot/config.h` |
| First power-up and tuning | `control/bringup.md` |
| How the robot works; open questions | `control/sequence.md` |

## Contents

0. [Read first: safety rules](#0-read-first-safety-rules)
1. [Mechanical assembly](#1-mechanical-assembly)
2. [Electrical assembly](#2-electrical-assembly)
3. [Building the software](#3-building-the-software)
4. [Loading the software onto the Mega](#4-loading-the-software-onto-the-mega)
5. [Operating and monitoring](#5-operating-and-monitoring)
6. [Quick reference](#6-quick-reference)

---

## 0. Read first: safety rules

1. **Plug or unplug anything with 12 V off.** That means every motor (the
   key motor cable included) and the drivers. A driver cut off from its
   supply while its motor turns can be damaged (TMC2209 datasheet §3).
2. **Power order:** USB first, then 12 V. To switch off: 12 V first, then USB.
3. **Emergency stop: pull the 12 V plug.** Typing `!` in the logger stops the
   current move and switches all drivers off. The button pauses a run after
   the current attempt.
4. **Keep forces low.** The lock has a relocker ("délateur") that blocks it
   for good if it's forced (`control/lock_research.md`). The firmware limits
   current and stops on stall, so never raise currents above what
   `control/bringup.md` sets.
5. **Fingers out of the gears** while 12 V is on.
6. **Fit drivers the right way round.** Match EN / DIR / VM / GND on the
   driver to the RAMPS silkscreen. A reversed driver is destroyed (BTT
   manual, safety note 1).

---

## 1. Mechanical assembly

There are two units:
- **Dial unit**: three motors turn the three dial plugs through 14T/28T
  gears. Each plug is on a spring-loaded shaft running in two 608 bearings.
  The Mega and RAMPS sit on a deck at the back.
- **Key turner**: one motor straight on the key axis. A printed cap slides
  over the key's bow.

Both hold to the door with 22 mm rubber-coated M4 pot magnets: 6 on the dial
unit, 3 on the key turner. Design history: `docs/housing_decisions.md`.
Renders (drawn before the magnet change): `cad/renders/dial_unit_v2_section.png`,
`cad/renders/dial_unit_v2_door_view.png`,
`cad/renders/key_turner_v1_overview.png`.

### 1.1 What to print

Print from the per-part STLs in `cad/`. Material and orientation are from
the print notes in `cad/dial_unit_housing.scad` (end of file) and
`cad/key_turner_housing.scad` (end of file).

| STL | Part | Qty | Material | Bed side |
|---|---|---|---|---|
| `dial_front_assembly.stl` | dial front plate: 6 magnet holes, 3 bearing bosses, 3 legs, pointer tab | 1 | PETG | door face |
| `dial_motor_sled.stl` | motor sled + 3 deck legs | 1 | PETG | inner face (spring pockets, countersinks); legs up |
| `electronics_deck.stl` | deck for the Mega, with the button hole + recess and its wire hole (rev 2026-10-09.1) | 1 | PETG | flat, mating face down (the recess bridges: no supports) |
| `dial_drivetrain.stl` | 3 gear-shafts + 3 pinions, one plate | 1 plate | **PETG-CF** | gear face / pinion hub. **Elephant-foot compensation on**, or the bottom layer of the teeth binds |
| `magnet_retainers.stl` | 10 retainer discs (9 needed) | 1 plate | PETG | flat |
| `key_turner_base.stl` | key-turner base + 3 legs | 1 | PETG | door face |
| `key_turner_motor_plate.stl` | key motor plate | 1 | PETG | inner face |
| `key_turner_cap.stl` | slotted cap | 1 | **PETG-CF** | slot mouth. **Elephant-foot compensation on** |
| `key_turner_hub.stl` | grooved motor hub | 1 | **PETG-CF** | groove face |

PETG-CF needs the hardened (tungsten carbide) hotend.

**Slicer:** Bambu Studio's default settings for the H2D, which is what
you've used so far (Paul, 2026-10-06). Turn on elephant-foot compensation
where the table says so.

**Don't print:**
- `dial_unit_housing.stl` and `key_turner_housing.stl`: whole-unit layouts
  that mix PETG and PETG-CF parts;
- `standoff_screw_fit_test.stl`, `printed_thread_test.stl` and
  `tube_socket_test_key_set.stl`: old test pieces;
- `Fichet_robot.3mf` and `dial_unit_housing.3mf`: pre-v2 geometry.

**Already printed and passed** (`docs/housing_decisions.md`):
- the door-pattern test (2026-10-05: "plate fits the door perfectly and all
  three dial turners turn easily");
- the key fit test (2026-10-06: the cap slides on and turns the key to its
  stop);
- the Mega base coupon (2026-10-04: 3 of 4 screws go in; 3 are enough).

**Magnet holes:** the dial front assembly and key-turner base you already
printed (22.4 mm holes) stay in use, with a 2-layer wrap strip on each
magnet (§1.3a). The current STLs have 21.7 mm holes, for any future reprint
(no strips needed then). Print the retainers if you haven't yet.

### 1.2 Hardware

| Item | Dial unit | Key turner | Status |
|---|---|---|---|
| 608 bearings (8 × 22 × 7) | 6 (2 per dial) | — | on hand |
| Compression springs ≤ 8 mm OD, ~18–20 mm free, solid < 10 mm | 3 | — | ordered: QUARKZMAN 0.5 × 7 × 20 mm, 304 stainless, arriving 2026-10-07 (Paul). Count the coils on arrival |
| M3 × 10 countersunk, hex socket (motor screws; the length includes the head) | 12 | 4 | on hand (kit has 55) |
| M6 countersunk self-tapping, 16 mm | 6 | 3 | on hand. On the key turner, 16 mm works better than the 20 mm the CAD notes listed (Paul, 2026-10-06) |
| M3 × 6–8, self-tapping into PETG (Mega base plate to deck) | 4 (3 go in) | — | on hand |
| M3 × 3 or × 4 **grub** screws (pinion / hub), optional | 3 | 1 | optional. **Never a cap screw**: its head would hit the gear |
| 22 mm rubber pot magnets, M4 back (Wukong) | 6 | 3 | ordered |
| M4 screws for the magnets | 6 | 3 | the ones in the magnet pack, if any. Otherwise **pan, button or socket head — not countersunk** (the retainer is flat). Length: see §1.3a. Any head up to 9 mm across and 6 mm tall clears the other parts on both units (CAD check, 2026-10-07) |
| Motors 17HE19-2004S | 3 | 1 | on hand (+1 spare) |

### 1.3 Checks before the big parts

1. **Magnets** (`docs/housing_decisions.md`, 2026-10-06):
   1. Measure one magnet's diameter, height and thread depth. If they're
      not 22 mm and 6 mm, tell me before printing: the holes are sized from
      the listing.
   2. **Pull test:** stick one magnet on the door and pull *sideways*
      (along the door) with the luggage scale. **If it slips under about
      0.8 kg**, the units need more magnets or a floor leg before the robot
      runs.

   Send me the three measurements and the slip force.
2. **Springs:** count the coils, and check the spring closes to under 10 mm.
3. **First M6 into a printed leg: drive it by hand**, not with a power
   driver, and check the leg doesn't crack. The legs have ~3.3 mm of wall
   around the 5.4 mm pilot (`docs/bom.md`).

### 1.3a Fitting the door magnets (both units)

How it works: each magnet sits in a **through hole** in the plate. On the
plate's inner face a raised **seat ring** (29 mm across) stands around each
hole. A flat printed **retainer disc** (27 mm, 3 mm thick) lies on the ring,
and an M4 screw through the retainer into the magnet's threaded back holds
the magnet up against it. The ring's top sets the depth, so the rubber ends
up 0.2 mm proud of the door face. On the door, the pull goes magnet →
screw → retainer → ring (`common_mounts.scad`, `rmag_*`). The dial front
plate has 6, the key-turner base 3.

**Measure first** (one magnet, calipers):
- **Diameter D.** Measured 21.5 mm (Paul, 2026-10-07). The holes are now
  **21.7 mm**, chosen from the fit-test strip (snug at 21.8, worked in at
  21.7): the rubber grips, so the magnet can't slide out of the inner side.
- **Height H: measured 6.0–6.1 mm, back flush, no boss** (Paul,
  2026-10-07). The rubber stands 0.2–0.3 mm proud: fine. For reference, the
  rule: the magnet's back must be
  level with the ring top (5.8 mm above the door face), so the rubber stands
  H − 5.8 proud. 5.9–6.3 mm is fine (0.1–0.5 proud). Under 5.9 the rubber
  would sit flush or below the plate; over 6.3 the dial plugs sit too
  shallow in the stars. Either way, tell me before fitting: it's one number
  in the CAD and a reprint.
- **Thread depth T** (depth rod into the threaded hole).
- **Screw length** = 3 (retainer) + T − 0.5, rounded **down** to a length
  you have. It must not bottom in the hole, or it stops before it clamps.
  Example: T = 4 → 6.5 → use M4 × 6.

**Before you start:**
- Work on a wooden or plastic table, no steel within ~20 cm. Keep the
  magnets apart: they snap together hard and pinch fingers.
- Look at every seat ring top. It sets the depth, so it must be flat:
  trim any string or blob with a blade. Trim any elephant's foot inside the
  hole at the door face too: the magnet has to go in from that side.
- Check the retainers: the screw should pass through the 4.5 mm hole freely.

**Which plates you have:**
- **Plates printed before 2026-10-07 (22.4 mm holes; the ones in use):**
  wrap each magnet's side once with a **2-layer wrap strip**
  (`cad/magnet_wrap_strips.stl`, 69 × 5 mm × 0.4 mm, PLA; Paul: "the
  2-layer version is perfect"). Wrap it round the middle of the magnet's
  side, ends overlapping, then follow the steps below. The strip goes into
  the hole with the magnet.
- **Plates reprinted from the current STLs (21.7 mm holes):** no strip.
  The hole grips the rubber directly.

Nine strips cover both units (6 + 3); print a couple of spares.

**Steps (per plate).** The hole grips the magnet, so its depth is set by
how far you press it in. The table sets it for you:
1. Lay the plate **inner face down** on the table, so the seat-ring tops sit
   flat on it.
2. From the door side, press a magnet into a hole, **threaded back first**,
   until its back stops on the table. Its back is now level with the ring
   top, and the rubber stands just proud of the door face. Press straight;
   a thumb is usually enough. If it's very stiff, press with a flat block of
   wood over the rubber.
3. Repeat for every hole, then turn the plate over (inner face up).
4. Lay a retainer on each ring, centred on the thread. It rests on the ring
   and on the magnet's back together.
5. Start the M4 screw by hand, then snug it with a screwdriver until the
   retainer can't turn. **Snug, not tight**: the retainer is PETG and the
   thread is in the magnet. No thread-locker (some attack plastic).
6. **Check:**
   - Every retainer sits flat on its ring, no gap.
   - Put the plate door face down on the table and slide a sheet of
     printer paper under its edge between two magnets: it should go under
     (the plate rests on the magnets, not on its face). Do it all round.
   - Turn the plate on its side and shake it gently: nothing moves.
     **Correction (2026-10-07):** an earlier version said a magnet moving
     inward was fine. It wasn't: in the old 22.4 mm holes the 21.5 mm
     magnets and their retainers fell out of the inner side when the unit
     was off the door (Paul). That's why the holes are now 21.7 mm.
7. **Order:** on the dial unit, fit the magnets before anything else (they're
   under the sled). On the key turner, before the motor plate goes on.

**Pull test (once, before the robot runs; §1.3 item 1):**
1. One magnet with its screw part-way in. Tie a loop of string round the
   screw under its head.
2. Stick the magnet flat on the door where the units go.
3. Hook the luggage scale in the loop and pull **along** the door face
   (sideways, not away from it), slowly, until it slides. Note the peak.
4. Three times, plus once pulling straight down. Send me all four readings.
   The units need ~0.8 kg sideways per magnet (1.5 kg dial unit on 6, with
   ~3× margin, `docs/housing_decisions.md` 2026-10-06). Below that, more
   magnets or a floor leg.

**Taking a unit off the door:** pull it straight off, peeling from one edge
if the magnets hold hard. Don't slide it: the dial plugs are in the stars
(§4, shutting down).

### 1.4 Dial unit

**ASSUMPTION: the order below is derived from the CAD.** The repo has no
written assembly order for the dial unit (the pointer to one in
`dial_unit_housing.scad` leads nowhere). Two things fix the order:
- the motor screws go in from the sled's inner face, so the motors must be
  on the sled before it's joined to the front;
- the magnets sit under the sled's outline, so they go in first.

Tell me if a different order works better, and I'll record it.

1. **Magnets.** Six, as in §1.3a: plate door face down, magnet rubber face
   down into each hole, retainer on top, M4 snug. Check with the paper test.
2. **Bearings.** Press two 608s into each boss from the back (the boss top).
   A 2 mm lip on the door side stops the outer ring. It's a light press fit
   (22.15 mm pocket).
3. **Gear-shafts.** Slide each gear-shaft into its bearings from the back,
   plug first. Its Ø11 spacer stops on the rear bearing's inner ring: that's
   the plug's forward position. Each shaft slides 7 mm back from there; it
   must slide freely.
4. **Motors on the sled.** Each motor goes on the sled's outer face, its
   front boss in the recess. Four M3 × 10 countersunk screws go in from the
   sled's **inner** face. Before tightening, turn each motor in 90° steps so
   its cable leaves into a free gap. Which motor is A, B and C follows the
   holes: A top-left, B top-right, C bottom. **Label each motor's cable.**
5. **Pinions.** Push each pinion onto its motor shaft, hub end first, until
   it stops. The D-shaped bore stops where the shaft's flat ends, and that
   sets its position. The grub screw is optional: the pinion is trapped
   between the sled and the boss tops.
6. **Springs.** Sit one spring in each gear's rear pocket (Ø8.6, 2 mm deep).
7. **Join sled to front.** Bring the sled down onto the three front legs.
   Each pinion has to mesh with its gear, and each spring has to go into
   the sled's pocket. The screw pattern is asymmetric, so it fits only one
   way. Drive three M6 countersunk (~16 mm) from the sled's outer face into
   the legs, the first by hand.
8. **Check by hand:**
   - Push each plug in from the door side. It should go back about 7 mm and
     spring forward again.
   - Turn each plug by hand from the door side, a full turn. It turns its
     motor through the gears, so expect the motor's slight notchiness, but
     no tight spot.
9. **Deck.** Three M6 countersunk (~16 mm) through the deck's top face into
   the deck legs. Do this *before* fitting the Mega base plate: two of the
   three screws sit under it (`docs/housing_decisions.md`, 2026-10-04).
10. **Mega.** Screw the Mega's plastic base plate to the deck with the M3
    self-tappers (3 of the 4 go in). Its position and turn are fixed by the
    pilot holes ("Jack/USB end faces up-right" in `dial_unit_housing.scad`).
    **VERIFY** that you can reach the USB and RAMPS connectors there; that
    hasn't been checked.
11. **Start/stop button** (revision 2026-10-09.1): it goes in from **under**
    the deck, left of the Mega next to the deck leg you can still see.
    1. Solder its two leads and heat-shrink them; long enough to reach the
       RAMPS endstop block (Y_MIN) via the 4mm wire hole beside it.
    2. Push the button up through the 7.4mm hole from below, so its body's
       wide base sits in the 10mm recess underneath.
    3. On top: the washer, then the nut, finger-tight plus a little. If the
       washer leaves too little thread, use the nut alone.
    4. Run the leads under the deck, clear of the motor cans, and up through
       the wire hole. Map: `docs/photos/deck_button_mount_topview.png`.

    **VERIFY:** the body clears the motor can below it, the nut starts, and
    the wire hole is clear of the base plate. The UART pigtail's splice
    (2.5) just zip-ties to the deck.

### 1.5 Key turner

From the notes at the end of `cad/key_turner_housing.scad`:

1. **Magnets.** Three, in the base, as in §1.3a (before the motor plate
   goes on).
2. **Motor onto the motor plate.** Four M3 × 10 countersunk from the plate's
   inner face.
3. **Hub onto the shaft.** Its D-bore sits entirely on the shaft's flat.
   Push it on until the shaft tip bottoms in the bore. The grub screw is
   optional.
4. **Plate onto the legs.** Three M6 × 16 countersunk self-tappers, the first
   by hand. That's 10 mm of thread in each leg, as on the dial unit.
5. **Cap.** It's a loose part that sits between the key and the hub: its
   slot takes the bow, and its tongue sits in the hub's groove. It lets the
   unit sit up to 2.7 mm off the key axis without side-loading the lock.
6. **Key motor cable.** Its own ~1 m cable runs to the dial unit and plugs
   into the RAMPS **E0** motor header (revision 2026-10-08.1 — the driver is
   on the RAMPS now, so there is no board to mount here). Leave the three
   magnet retainers reachable; zip-tie the cable clear of the rotating cap.

### 1.6 Putting the units on the door

1. **12 V off**, key motor cable unplugged from E0.
2. **Key** in the lock by hand, at its start position (bow vertical).
3. **Dial unit:** pointer tab **up** (it points at the top pair of holes).
   Bring it straight onto the door over the three dial holes and let the
   magnets take it. A plug that doesn't line up with its star is pushed
   back on its spring; the plate still seats flat. The robot's seat routine
   turns each plug slowly until it drops in.
4. **Key turner:** turn the cap so its two roof marks are **top and bottom**
   (its slot is then vertical, like the bow). Slide the unit straight on
   over the key. The keyhole is about 125 mm left of the dial-cluster
   centre, and the base reaches 43 mm toward the dials, so the two units
   don't touch.

   **VERIFY:** the cap's tongue sits in a through-groove in the hub, so the
   cap may slide out while you hold the unit. If it does, put the cap on the
   bow first (marks top and bottom), then slide the unit on. Turn the hub
   by hand (motor unpowered) until its groove takes the cap's tongue.
5. Plug the key motor cable into the RAMPS E0 motor header. Zip-tie it at the
   key turner and near the RAMPS, clear of the cap.

### 1.7 Mechanical items still open

- Magnet pull test (1.3), and whether the magnets alone hold the units.
- Reprint the dial front assembly and key-turner base with magnet holes.
- Button mount: designed (revision 2026-10-09.1, 1.4 step 11); check it on
  the reprinted deck. (Revision 2026-10-08.1 removed the remote-board mount;
  2026-10-08.2 removed the hub board, so it needs no mount either.)
- Access to the Mega's connectors at its position on the deck.
- Only if the first full run fails: a key turner that pulls the key out and
  pushes it back in at every attempt (`control/sequence.md`, Open items).

---

## 2. Electrical assembly

The full design, with sources, is `control/wiring.md`. **Print
`control/harness/schematic.pdf`** (the full schematic in colour) and keep
`control/harness/ramps_and_uart.md` (one bench sheet of everything on the
RAMPS, and the UART pigtail) beside you. Other drawings:
`control/harness/overview.svg` (block diagram),
`control/harness/uart_pigtail.svg` (the pigtail) and
`control/harness/harness.png` (the pigtail leads and the key motor cable).

**Revision 2026-10-08.1 (2026-10-08):** all four drivers now sit in RAMPS
sockets — the key in **E0**, beside the three dials. There is no remote
driver board and no inter-unit signal cable; the only wire between the units
is the key motor's own cable, into the E0 motor header.

**Revision 2026-10-08.2 (2026-10-08):** the hub board is replaced by the
**UART pigtail**: six leads, R1 in line in the TX2 lead, one solder splice
(2.5). See `docs/revisions.md`.

### 2.1 Build it in bring-up order

Don't wire everything and then switch on. Each block below is tested by a
bring-up stage before the next one is added:

| Build | Then test with |
|---|---|
| 2.3 Drivers: cut the EN-end pins underneath (all four), heatsinks. Flash the firmware (section 4) | `control/bringup.md` stage 0 |
| 2.4 Mega + RAMPS + the four drivers; 2.5 UART pigtail; 2.6 power; 2.7 jumpers | stage 1 (one driver, then all four) |
| 2.8 one motor on the bench | stages 2 and 3 |
| Dial unit assembled (section 1) with its three motors | stage 4 |
| Key motor cable to E0, key turner (section 1) | stage 5 |
| Everything on the door | stage 6 (short dry run) |

### 2.2 Tools and parts

- Soldering station, solder, flush cutters, heat shrink and heat gun,
  calipers, a marker.
- **Multimeter** (you have one). Use it to check the DC-jack adapter's
  polarity before the first power-up, and the UART pigtail (2.5).
- Masking tape, for the pigtail's lead labels.
- Parts: **`docs/bom.md`, "Electronics assembly — every discrete part"**
  lists each one. What you fit beyond what's already on the boards is small
  (revision 2026-10-08.2):
  - **R1, 1 kΩ**, in line in the UART pigtail's TX2 lead (the only UART
    resistor), and heat shrink;
  - the **DC-jack-to-screw-terminal adapter** (5.5 × 2.1 mm) and **20 AWG**
    red + black wire, PSU → RAMPS "5A" terminal;
  - about **20 F–F jumpers** and the 7 mm **start/stop button**.

  The fuses, diode, capacitors and resistors drawn in grey on the schematic
  are already on the RAMPS. **No longer used** (bought earlier; keep as
  spares): the 1.1 A PTC and the fuse kit + printed holder, the two 100 µF
  capacitors, the 6-conductor cable and the Phoenix connectors, the female
  header strips; and (2026-10-08.2) the hub's perfboard and male header
  pins.

### 2.3 Prepare the drivers (BTT TMC2209 V1.3)

Four drivers are used (three dials + the key), plus one spare.

1. **Two snips per driver, on all four** (`control/wiring.md` §3.3), before
   the heatsinks. Revision 2026-10-08.2: no soldering on the drivers.
   1. At the EN end, two pins go through the board (above and below). Cut
      the **bottom** ends of both off flush underneath. Leave the top ends.
   2. Find **DIAG** on top: the EN-end pin next to the trimmer pot, with
      "DIAG" printed under it. Its DIAG lead (2.7) clips onto its top.
   3. Find **RX** on top: the 4th pin from EN (EN, MS1, MS2, **RX**, TX, CLK,
      …), one of the three tall pins. Its UART lead (2.5) clips onto its top.
      Nothing ever goes on TX or CLK.

   (Leave the spare untouched.) Stage 3 confirms DIAG electrically.
2. **Heatsinks** on all drivers you'll use. At ≤ 1 A RMS no fan is needed
   (BTT: active cooling above 1.2 A).
3. **Don't bridge R10** on any driver (`control/wiring.md` §2).
4. **VREF pot to minimum on every driver**, set by measurement in bring-up
   stage 1 step 3a (12 V on, no motor, driver off): DC volts from the pot's
   metal centre to GND, turn the way the reading falls until it stops. The
   firmware sets the current over UART, but a driver whose 12 V drops out
   for a moment comes back using its pot, until the firmware notices at the
   end of that move (`control/wiring.md` §7). BTT's manual doesn't say
   which way is minimum, so measure rather than turn it to a stop.

### 2.4 Mega, RAMPS and the four drivers

RAMPS 1.4 layout

*RAMPS 1.4 layout, matching Paul's Fasizi board. Illustration by José L.
Cuevas, [RepRap wiki, File:Rampsv14_wiring_bed.png](https://reprap.org/wiki/File:Rampsv14_wiring_bed.png),
used under the [GNU Free Documentation License](https://www.gnu.org/licenses/fdl-1.3.html)
(the wiki's licence for its content). The bed heater and thermistor wiring
drawn in it are not used by this robot.* Hold the board as drawn (power terminals on the left): **E0** is
the top-left socket, X/Y/Z the bottom row, the endstop block (X-MIN …
Z-MAX; rows S, −, +) top right, and AUX-4 (D16 at the top) down the right
edge.

*One-sheet summary of everything on the RAMPS, and the pigtail:
`control/harness/ramps_and_uart.md`.*

1. **RAMPS jumpers**, under the X, Y, Z and E0 sockets. They set each
   driver's UART address:

   | Socket | Role | MS1 | MS2 | MS3 | Address |
   |---|---|---|---|---|---|
   | X | dial A (top-left) | off | off | **off** | 0 |
   | Y | dial B (top-right) | **on** | off | **off** | 1 |
   | Z | dial C (bottom) | off | **on** | **off** | 2 |
   | **E0** | **key** | **on** | **on** | **off** | **3** |

   **Never fit an MS3 jumper.** On the V1.3 the MS3 position is the UART
   line, and a jumper there would tie it to 5 V.
2. **Check which way the drivers go**, before the RAMPS goes on the Mega.
   There's no square pad or pin-1 dot on top, but the silkscreen has small
   **EN** and **GND** labels at the sockets (Paul found them, 2026-10-08):
   the driver's EN pin goes at the EN label, its GND pins at the GND labels.
   That settled it for Paul. If the labels are hard to read, cross-check
   with the multimeter (power off, no drivers, continuity), **X** socket:
   1. Underneath, look for a **square** solder pad on each socket: that's
      pin 1, **EN**.
   2. "5A" terminal **−** to each hole of the socket row nearer the X motor
      header: **two** beep, one at each end. Those are the driver's GND pins.
   3. "5A" terminal **+** to the end hole beside a GND hole: beeps (through
      the RAMPS fuse; a low resistance reading is fine). That's **VS**.
   4. Each X motor-header pin beeps to one of the four middle holes of that
      row.

   So the row nearer the motor header takes the driver's **VS, GND, A2, A1,
   B1, B2, VIO, GND** side, and EN sits directly across from VS. Repeat step
   2 on Y, Z and E0. (From the RAMPS 1.4 KiCad layout; your Fasizi board is
   checked by these readings.) **Send back:** the X results and whether you
   saw the square pads.
3. Press the RAMPS onto the Mega.
4. Plug each driver in: **VS/GND/motor side in the row nearer that socket's
   motor header**, EN across from VS. A reversed driver is destroyed. The
   key driver goes in **E0, the top-left socket** (power terminals on the
   left); **E1, top-right, stays empty**. X, Y, Z are the bottom row, left
   to right (`control/harness/ramps_and_uart.md` A2).
5. **Mount the Mega**: four M3 × 6–8 screws through the Mega's own plastic
   base into the electronics deck (three are enough).

### 2.5 UART pigtail (replaces the hub board, revision 2026-10-08.2)

Six leads, each ending in a female Dupont, joined in one solder splice. R1
sits in line in the TX2 lead. No 12 V, 5 V or GND on it. Drawing:
`control/harness/uart_pigtail.svg`; reference `control/wiring.md` §5.

1. **Measure**, with the drivers seated: AUX-4 to each driver's **RX** pin
   (X, Y, Z, E0). Pick a splice point near the middle of the RAMPS. (A
   female Dupont on top of RX is checked: it grips and conducts, Paul
   2026-10-08.)
2. **Make six leads**: cut one end off each of six F–F jumpers (halves will
   do if long enough). Cut each to its measured length + a few cm.
3. **TX2 lead:** solder **R1 (1 kΩ)** in line, ~3 cm from the female end.
   Heat shrink over it.
4. **Splice:** R1's far lead + RX2 + A + B + C + KEY in one joint. Heat
   shrink over it, then a larger piece over the bundle.
5. **Label** each female end with tape: TX2, RX2, A, B, C, KEY.
6. **Check (multimeter on Ω), pigtail loose:**
   - TX2 → RX2: about **1 kΩ**
   - TX2 → A, B, C, KEY: about **1 kΩ** each
   - RX2 → A, B, C, KEY: about **0 Ω** each

   Then tug each lead at the splice.
7. Fit the leads in 2.7; zip-tie the splice to the deck.

**Send back:** whether the test-fit in step 1 worked, and the readings from
step 6.

### 2.6 Power wiring

PSU (Ledmo HTY-1200500, 12 V 5 A, 5.5 × 2.1 mm barrel, centre +) → DC-jack
adapter → **RAMPS "5A" terminal**, 20 AWG red for + and black for −. That's
all: the RAMPS's own 5 A fuse feeds all four drivers. Nothing else takes
12 V. Leave the **11A** terminal (heated bed) empty.

**Leave the Mega's own barrel jack empty.** It feeds only the Mega (VIN);
the drivers get 12 V only through the "5A" terminal, and diode D1 passes
power from there to VIN, never back. A PSU in the Mega's jack would run the
Mega but leave every driver missing on `ping`.

**Check the adapter's + / − with the multimeter** before the first power-up.

### 2.7 Signal jumpers on the RAMPS

DIAG leads and the button: F–F jumpers about 10 cm long. Pigtail leads: as
built in 2.5. The endstop headers are **S** (signal), **−** (GND) and **+**
(5 V).

| From | To |
|---|---|
| Top of dial A driver's **DIAG** pin (X socket) | **X_MIN S** (D3) |
| Top of dial B driver's **DIAG** pin (Y) | **X_MAX S** (D2) |
| Top of dial C driver's **DIAG** pin (Z) | **Z_MIN S** (D18) |
| Top of the **key** driver's **DIAG** pin (E0) | **Z_MAX S** (D19) |
| Pigtail leads **A, B, C, KEY** | top of the **RX** pin of the drivers in X, Y, Z, **E0** |
| Pigtail leads **TX2 / RX2** | AUX-4 pin 18 / 17 (D16 / D17) |
| Start/stop button (7 mm; leads up through the deck's wire hole) | **Y_MIN S** and **Y_MIN −** (D14) |

DIAG leads are plain F–F jumpers (revision 2026-10-08.2; no cut-in-half
leads). Before unplugging a driver, pull its DIAG and RX leads off. The
button mounts on the deck (1.4 step 11); a loose button on its leads is fine
for the bench.

**One connector for the endstop block** (Paul, 2026-10-09): three 6-pin
female header strips glued side by side into one **3-row x 6** block that
covers X_MIN … Z_MAX on all three rows. S row: DIAG A, DIAG B, button,
(empty), DIAG C, DIAG key. GND row: the button's second lead under Y_MIN.
The 5 V row stays empty. Three rows (not two) so it can't sit one row off
(that would short the button across 5 V). Mark the X_MIN end; glue only the
touching faces, set it on the header itself; continuity-check every lead
before the first power-up.

### 2.8 Motors

- **Dials**: dial A's motor on the **X** motor header, B on **Y**, C on
  **Z** (Z has two headers in parallel: use either, not both). Each header is
  the 4-pin one above its socket, labelled 2B 2A 1A 1B.
- **Before plugging any motor in, check its coil pairs with the multimeter**
  and make sure each pair sits at one end of the plug
  (`control/harness/ramps_and_uart.md` A5). Pins 2B–2A take one coil, 1A–1B
  the other. Which way round the plug goes only sets that motor's direction,
  which the firmware sets anyway; put them all on the same way (e.g. black
  toward 2B) and note it.
- **Key**: the key motor's own ~1 m cable plugs into the **E0** motor header
  (revision 2026-10-08.1 — no remote board). It's the only wire between the
  two units. Use the supplied cable as it is; shorten it only if the key's
  StallGuard reads too dull in stage 5. Zip-tie it at the key turner and near
  the RAMPS so a tug lands on the ties, and keep the spare length clear of
  the key cap.
- If a motor **buzzes or jitters instead of turning**: 12 V off, then swap
  the two middle wires in its connector. Some 17HE19-2004S have them swapped.
- **Never plug or unplug a motor with 12 V on**, the key motor included.
- Currents are set over UART (pots at minimum): dials 1.0 A RMS; the key
  starts at 0.6 A and stage 5 sets its final value.

---

## 3. Building the software

There are three pieces:

- **The firmware** (`control/firmware/safe_robot/`) runs on the Mega.
- **The logger** (`control/firmware/tools/logger.py`) runs on your Mac. It
  saves every line the robot prints and lets you type commands.
- **Host tests** (`control/firmware/test/`) are optional. They check the
  firmware's logic on the Mac against a simulated lock.

Written for a Mac (Paul, 2026-10-06).

### 3.1 Get the code

- With git (it comes with the Mac's command-line tools):
  `cd ~ && git clone https://github.com/paulforrester/fichet-safe-robot.git`
  makes the project folder `~/fichet-safe-robot`. Every command in this
  manual that names `control/…` or `cad/…` runs from that folder.
  To update later: `git checkout main`, then `git pull`.
- Without git: on the repo's GitHub page, Code → Download ZIP.

Always build from `main` after I tell you a PR is merged.

### 3.2 Arduino IDE (once)

1. Install Arduino IDE 2 from arduino.cc.
   **Apple Silicon Mac (M1/M2/…): install Rosetta 2 first.** The AVR
   compiler the board package installs is built for Intel Macs; without
   Rosetta, Verify fails with "avr-g++: bad CPU type in executable" (Paul,
   2026-10-09; Arduino forum). Check: `pgrep -q oahd && echo installed ||
   echo missing`. Install: `softwareupdate --install-rosetta
   --agree-to-license`. Then restart the IDE.
2. Tools → Board: if **Arduino Mega or Mega 2560** isn't listed, open
   Boards Manager and install **Arduino AVR Boards**.
3. Tools → Manage Libraries → search **TMCStepper** (by teemuatlut) → choose
   version **0.7.3** → Install. That's the version the firmware was built
   and checked against; `control/firmware/README.md` says why. SPI,
   SoftwareSerial and EEPROM come with the board package.

### 3.3 Compile

1. File → Open → `control/firmware/safe_robot/safe_robot.ino`. The IDE
   also compiles everything under `safe_robot/src/`. Those files don't
   show as tabs, which is normal.
2. Tools → Board → **Arduino Mega or Mega 2560**. Tools → Processor →
   **ATmega2560 (Mega 2560)**.
3. Click **Verify** (✓). Expect "Sketch uses about 51 KB (20%) of program
   storage space" and "Global variables use about 1.4 KB (16%)". The
   checked build gave 51,480 and 1,356 bytes; the IDE's compiler may differ
   by a little. Any error means something's wrong: send me the text.

### 3.4 Changing settings

- **Every value that isn't measured yet is in
  `control/firmware/safe_robot/config.h`**, in one block, with where each
  came from. Bring-up gives the real numbers. I'll normally send them as a
  PR. If you edit it yourself, change only the numbers and recompile.
- To try a value without recompiling, use `set <name> <value>` in the
  logger (the names are in `control/firmware/README.md`). It's lost at the
  next reset, so copy the good value into `config.h` afterwards.

### 3.5 The logger (once)

The logger needs Python 3 and pyserial. Install pyserial in its own folder
(a "venv") so it can't clash with anything else on the Mac:

```
python3 -m venv ~/safe-robot-venv
~/safe-robot-venv/bin/python -m pip install pyserial
```

If `python3` asks to install the command-line developer tools, say yes. To
check, **from the project folder** (the paths are relative to it; `git
clone` makes `fichet-safe-robot`, Download ZIP makes
`fichet-safe-robot-main`):

```
cd ~/fichet-safe-robot
~/safe-robot-venv/bin/python control/firmware/tools/logger.py --help
```

Run from anywhere else, it fails with "can't open file … logger.py" (Paul,
2026-10-09).

### 3.6 Host tests (optional)

These need the command-line tools (`xcode-select --install`). From the repo
folder:

```
make -C control/firmware/test
~/safe-robot-venv/bin/python -m pip install pytest
~/safe-robot-venv/bin/python -m pytest control/firmware/tools
```

The `pip install pytest` line is needed only the first time. (Correction,
2026-10-09: it used to carry a `# once` comment on the same line, which the
Mac's zsh passes to pip as package names, so the install failed.)

Expect `53 tests, 36489 checks, 0 failures` and `3 passed`. I check these
in every PR (also built with clang, which is the Mac's compiler). Running
them yourself is only needed if you change the code.

---

## 4. Loading the software onto the Mega

### 4.1 Upload

1. **12 V off.** Connect only the USB cable (USB-C → USB-B). The RAMPS can
   stay on the Mega.
2. Close the logger and the IDE's Serial Monitor. Only one program can use
   the port, and an open port makes the upload fail.
3. Tools → Port → the Mega. On a Mac it looks like
   `/dev/cu.usbmodemXXXX (Arduino Mega or Mega 2560)`. The genuine Mega
   needs no driver.
4. Click **Upload** (→). It compiles, then uploads. Expect "Done
   uploading".

### 4.2 Check it's the right build

1. Start the logger (5.3). Opening the port restarts the Mega.
2. The first line is
   `# Fichet safe robot 0.4 (2026-10-08, rev 2026-10-08.1) - type help`. If it
   says 0.3 or older, the old code is still on the Mega.
3. Type `status`. Expect `# state=IDLE run=… next=…`.
4. Type `cfg` to see the settings it was built with.

### 4.3 What an upload keeps

**An upload doesn't erase the stored progress or calibration.** They live in
the Mega's EEPROM, and the upload writes only program memory. The IDE runs
avrdude with `-D` and only a flash write (Arduino AVR core 1.8.6
`platform.txt`), and the Mega's bootloader refuses a chip erase
(`stk500boot.c`).

- If the new build changes a setting that defines the dial positions,
  `resume` stops with `CFGHASH`. Those settings are the dial directions,
  steps per turn, gearing, microsteps, positions per dial, home modes and
  click-finding on/off (and the home offsets, if click-finding is off).
  Then:
  - `resume force` if you know the positions still mean the same;
  - otherwise `reset yes` and start over.
- To wipe the stored progress on purpose: `reset yes`. The calibration is
  kept and re-measured every session anyway.

### 4.4 If the upload fails

- "Port busy", "not in sync" or "programmer is not responding": close the
  logger or Serial Monitor. Check the port, then retry.
- No port listed: try another USB cable (some are charge-only) or another
  USB port.
- **No green ON LED at all on USB**: no 5 V is reaching the Mega. Test the
  bare Mega (RAMPS off) on the 12 V supply in its own barrel jack, for this
  test only: if the LED lights, the Mega is fine and the USB cable is bad.
  Paul's first USB-C → USB-B cable did exactly this (2026-10-09); a USB-A →
  USB-B printer cable plus a USB-C → USB-A adapter fixed it. (Unplug the 12 V
  from the Mega's jack afterwards: in the robot it stays empty.)

---

## 5. Operating and monitoring

### 5.1 Before the first real run

1. Complete `control/bringup.md` stages 0–6, sending me what each stage asks
   for.
2. I send back a `config.h` with the measured values (directions, key
   current, classification bands). Upload it (section 4).
3. Run `calibrate` once with everything on the door, as in 5.4.

**The biggest unknown:** whether a combination dialled with the key already
in counts. The safe's own manual dials with the key out
(`control/sequence.md`, Open items). The first full run is the real test.

### 5.2 Setting up for a session

Placing the units is described in more detail in 1.6.

1. 12 V off.
2. **Key:** insert the real key (it goes in one way only) and leave it at
   its start position. If it was left turned, turn it back anticlockwise by
   hand until it stops.
3. **Dial unit:** place it over the three dial holes, A top-left, B
   top-right, C bottom, and let the magnets take it. Plugs that don't line
   up with their star get pushed back on their springs. That's expected:
   the session start seats them.
4. **Key turner:** cap roof marks top and bottom, slide it over the key's
   bow, and let the magnets take it.
5. Plug the key motor cable into E0 (12 V still off).
6. USB to the Mac. Start the logger (5.3).
7. 12 V on.
8. Type `ping`. Expect four lines starting `DRV,A,1,21`, `DRV,B,1,21`,
   `DRV,C,1,21` and `DRV,K,1,21`. The `1` means the driver answered; `21` is
   its version.

### 5.3 Starting the logger

```
cd ~/fichet-safe-robot
ls /dev/cu.usbmodem*
caffeinate -i ~/safe-robot-venv/bin/python control/firmware/tools/logger.py --port /dev/cu.usbmodemXXXX
```

The `ls` line lists the Mega's port; put that name in place of
`/dev/cu.usbmodemXXXX`.

- **`caffeinate -i`** stops the Mac from sleeping while the logger runs.
  Keep the Mac on its charger with the lid open.
- **Files:** `runs/<date-time>_raw.log` holds every line, with the Mac's
  time; `runs/<date-time>_attempts.csv` has one row per attempt. Both grow
  as the run goes, so a crash or Ctrl-C loses nothing already written.
- **Commands:** type them in the logger window and press Return. `!` aborts
  at once.
- **On screen:** progress lines (`EV`, `ERR`, `GSTAT`, `HOME`, `LEARN`,
  `CAL`, `RECHECK`, `SUCCESS`, …), every attempt that isn't a clean fail, and
  every 50th attempt. A success also rings the terminal bell.
- **Opening the port restarts the Mega** (Arduino auto-reset). So start the
  logger *before* `start`, and don't quit and restart it during a run. If
  you do, the run stops, its progress is safe in EEPROM, and `resume`
  continues it.

### 5.4 Starting a run

**The very first time** (or if you get `TUNE … no key calibration yet`):
with the key at its start, type `calibrate`. It:
- turns the key 60° and back, onto its rest stop;
- seats the dials and turns each one once clockwise;
- homes each dial, prints `CAL` and `OFFSET` lines, and saves the result.

It ends with `# calibration saved`.

**A new run:** `start`, or press the button when nothing is stored. If a run
is already stored, `start` refuses: use `resume`, or `reset yes` to throw
the old run away.

**Continuing a stored run:** `resume`, or press the button.

Either way the robot first does the **session start**, about 40 s
(estimate):
1. checks all four drivers;
2. finds the key's rest stop (it searches up to 180°, because the key stays
   wherever it was left) and calibrates the key;
3. seats the dials, then turns each one free once to measure its load and
   find its clicks;
4. homes each dial on its stop, twice;
5. learns **N**, the angle where the key stops with a wrong combination
   (3 tries; `NSTOP` line).

Then the attempts begin (`EV,…,RUN,…`).

### 5.5 What a run does

- **Each attempt** turns **one dial by one click** (serpentine order, so no
  dial ever wraps from 20 back to 1). It then turns the key to N + 15°,
  records the angle reached, turns the key back to its start, and saves
  progress.
- **Every 200 attempts** it re-checks: it re-homes the dials and re-learns N.
  If anything moved, it stops and rewinds to the last good check (5.8).
- **8,000 combinations** in all.
  - **Time (estimate, not measured):** from the `config.h` speeds, motor
    movement alone is about 0.8 s per attempt, so about 1.8 h for all
    8,000, plus the re-checks. On average the right combination comes
    halfway. Stage 6 measures the real time.

### 5.6 Monitoring

- **Logger window:** a line every 50 attempts, for example
  `14:02:11 attempt 1250 4-13-7 101.3 deg (+0.4) CLEAN  [1250 logged]`.
  The `+0.4` is how far past N the key got, in degrees.
  Any non-clean attempt prints straight away.
- **`status`** works mid-run:
  `# state=RUN run=1 next=1250 verified=1200 attempts=… N=101.0 homed=ABCK`.
  `next` is the next combination; `verified` is the last good re-check.
- **LED**, the Mega's "L" LED (it may be hidden under the RAMPS):
  - fast blink: running;
  - slow blink: idle, paused, or all combinations done;
  - steady: success;
  - double blink: error.
- **Watch and listen** during the first runs: nothing should slide on the
  door, and no dial should ever move while the key is turned.

Attempt classes, all relative to this session's N (`config.h`;
stage 6 sets the bands):

| Class | Key reached | Robot does |
|---|---|---|
| CLEAN | up to N + 4° | next combination |
| FALSESET | between N + 4° and N + 10° | logs it and carries on. The raw angle is kept for later |
| SUCCESS | N + 10° or more | stops and holds the key (5.10) |
| EARLY | below N − 8° | retries. Three in a row: stops with `EARLY` (5.9) |

### 5.7 Pausing, stopping, aborting

| You want to | Do |
|---|---|
| Stop cleanly (to leave it, or move something) | press the button, or type `pause`. It finishes the attempt, re-checks, then switches the drivers off. Nothing is lost |
| Stop a move *now* | type `!` (or `abort`). Drivers off; `resume` continues from the last check |
| Emergency | pull the 12 V plug |
| Finish for the day | `pause`, wait for it, then 12 V off, then USB |

A run can be left paused with power off for as long as you like. Progress is
in EEPROM.

### 5.8 Resuming after a pause, power cut, reset or re-seat

1. Make sure both units are seated on the door. If one was knocked, re-place
   it.
2. Power up in order (USB, logger, 12 V).
3. Type `resume` (or press the button). It redoes the session start, rewinds
   to the last good re-check (≤ 200 attempts redone), and carries on.

After a power cut mid-attempt the key may be left turned. That's fine: the
session start finds its rest stop from anywhere in its travel.

### 5.9 Errors

An error prints `ERR,<time>,<code>,<text>`, switches all drivers off, and
double-blinks the LED. Fix the cause, then `resume` (or `ping`, to clear
the error before a bench command). If you're not sure, send me the raw log.

| Code | Meaning | What to do |
|---|---|---|
| DRIVER | a driver didn't answer, or has the wrong address | 12 V on? Cable plugged? UART leads and jumpers (2.4, 2.8)? Then `ping` |
| CONFIG, DIR | a driver setting didn't read back over UART | check the UART leads; `ping`; retry |
| DIAG | a stall line was already high before a move | DIAG lead off, or driver fault. Check the lead; `ping` shows both readings |
| TUNE | no stall threshold, or no key calibration yet | `calibrate`, with the key at its start (5.4) |
| KEYHOME | the key found no rest stop | key not inserted, or the cap slipped off the bow? Re-seat; `resume` |
| KEYCAL | key calibration failed | key not at its start? Turn it back by hand; `resume` |
| SGCAL | a dial's calibration turn failed | plug jammed or not seated? Re-place the dial unit; `resume` |
| HOME, HOMEREP | homing didn't find the stop, or the two passes disagree | plug not seated, or the unit moved. Re-place; `resume` |
| JAM | unexpected stall mid-move | something blocking? Look, clear it, `resume` |
| TIMEOUT | a move took too long | `resume`; if it repeats, send me the log |
| KEYOUT | refused to turn dials with the key out of rest | a protection. `resume` (the session start homes the key) |
| LEARN | N didn't repeat within 5° | key turner loose? Re-seat; `resume` |
| EARLY | the key stopped well short of N three times | a unit has moved. Re-seat both; `resume` |
| RECHECK | a re-check found a dial home or N moved | it has already rewound to the last good check. Re-seat; `resume` |
| CFGHASH | dial position settings changed since the run started | see 4.3 |
| NOHOME | (only if a dial's home mode is set to "no stop") | `resume force` or `reset yes` |
| DRVFAULT | a driver reset or reported a fault. The `GSTAT` line just before says which driver and what (below) | fix the cause, then `resume`. In a run it has already rewound to the last good check |
| ABORT | you typed `!` | `resume` when ready |

**`GSTAT,<time>,<driver>,<value>,<when>`** comes just before a `DRVFAULT`.
`<driver>` is A, B, C or K (key). The robot checks every driver before and
after each of its moves and before each attempt, because a driver whose power
dips comes back with no current setting and no stall detection. Without the
check, the key could then turn without stopping, and that looks like a
success. `<value>`:
- `1`: the driver **reset**: its 12 V (or its 5 V) dropped out for a moment.
  Type `ping`: the second-to-last field of each `DRV` line is that driver's
  GSTAT, so it shows which ones reset.
  - Only one driver: that driver's seating in its socket (push it down
    with 12 V off).
  - All four: the 12 V supply, its plug, or the RAMPS "5A" terminal screws.
  - Check those contacts with 12 V off (multimeter on continuity, while
    you wiggle them), fix, then `resume`.
- `2`: the driver shut itself down: **overheated or a short**. 12 V off, let
  it cool, check the motor's wires, and send me the log before resuming.
- `4`: its **12 V is too low** right now: the supply or its wiring.
- `80`: **no answer**: no 12 V at that driver, or its UART pigtail lead is
  off its RX pin. All four at once: the RAMPS 5 A fuse or the supply, or the
  pigtail's TX2 / RX2 leads, R1 or the splice (redo the 2.5 multimeter
  check).
- Flags add up: `5` = 1 + 4.
- On the bench, if you switched the 12 V off and on yourself since the last
  command (without `release`), a `1` is expected: run the command again.

`<when>` is `before` or `after` (a move of that driver), `attempt` (the check
before each attempt) or `config` (before its settings are written again).

### 5.10 Success

The logger rings and prints:

```
SUCCESS,<time>,<index>,<a>,<b>,<c>,<key deg>,<doorA>,<doorB>,<doorC>
```

The robot holds the key where it got to. The success is saved in EEPROM,
so it's shown again at every restart until `reset yes`.

1. **Write the combination down**: dials A, B, C as positions 1–20 (see
   below). Keep the raw log.
2. Type `release`. The motors switch off, and the key stays where it is
   (no spring back).
3. 12 V off, then take the key turner off its magnets. Don't turn the key
   back, and leave the dial unit where it is.
4. As the safe's manual says: turn the key on clockwise by hand, then
   **pull on the key** to open the door.
5. **Before you ever close the door again**, check you can do it by hand
   with the door open: dial the combination, insert the key, and turn it
   clockwise past ~100°.

**Positions:** there are no marks on the door, so the robot counts clicks.
To set position *p* on a dial by hand, turn it anticlockwise until it
stops, then clockwise, counting clicks: position *p* is the *p*-th click.
If a click sits right at the stop, the robot doesn't count it. So **if the
hand-dialled combination doesn't work, try one click either side on each
dial**.

### 5.11 All 8,000 tried, no success

The run ends with `EV,…,DONE` and the state shows `DONE`.

1. Run `logger.py --analyse` on the run's attempts CSV (5.12).
2. Send me both run files.

The first suspect is the biggest unknown above: a combination dialled with
the key in may not count. The next suspects are a dial parked between
clicks, and the success band. The angles logged on every attempt let us
tell these apart.

### 5.12 After a run: analysis and what to send

```
~/safe-robot-venv/bin/python control/firmware/tools/logger.py --analyse runs/<stamp>_attempts.csv
```

It re-classifies every attempt from its raw angle, using the spread of this
run's clean fails. It prints the counts and the 20 attempts that got
furthest past N. A false set or a near-miss shows up there.

Send me the `runs/<stamp>_raw.log` and `_attempts.csv` from any run that
did something unexpected.

If you lost the CSV, rebuild it from the raw log:
`logger.py --replay runs/<stamp>_raw.log`.

### 5.13 Taking the robot off the door

1. `pause` (if running), wait for it, then 12 V off, then USB.
2. Unplug the key motor cable from E0.
3. Pull each unit straight off the door, peeling from one edge if the
   magnets hold hard. Don't slide it along the door: the plugs are in the
   stars.
4. Turn the key back to its start by hand and pull it out. It only comes
   out at the start.

---

## 6. Quick reference

**Power:** on = USB, logger, 12 V. Off = 12 V, then USB. Never plug or
unplug with 12 V on. Emergency: pull the 12 V plug.

**Session:** key in at its start → dial unit on → key turner on → cable →
USB → logger → 12 V → `ping` → `resume` (or `start` for a new run; the
first time ever, `calibrate` first).

| Command | What |
|---|---|
| `help`, `status`, `cfg` | list commands; state and progress; settings |
| `ping` | check all four drivers |
| `calibrate` | key + dials, saved to EEPROM (key must be at its start) |
| `start` | new run from combination 0 |
| `resume [force]` | continue the stored run |
| `pause` or the button | stop after this attempt, re-check, drivers off |
| `!` or `abort` | stop the current move now, drivers off |
| `release` | all drivers off (also lets go of the key after a success) |
| `reset yes` | erase the stored progress |
| `seat`, `home [A\|B\|C]`, `learn`, `goto a b c`, `try`, `key <deg>`, `jog`, `sg`, `set` | bench commands: `control/firmware/README.md` and `control/bringup.md` |

**LED:** fast blink running · slow blink idle, paused or done · steady
success · double blink error.

**Logger:** `caffeinate -i ~/safe-robot-venv/bin/python
control/firmware/tools/logger.py --port /dev/cu.usbmodemXXXX`.

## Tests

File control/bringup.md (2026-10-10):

# Bench bring-up plan

> **Revision 2026-10-09.1** · key driver on the RAMPS E0 socket; UART pigtail · log: `docs/revisions.md`

Seven short stages, in order. Each ends with **"Send back"**: the numbers or
log lines I need to fill in `control/firmware/safe_robot/config.h`.

Wiring is in `control/wiring.md`; firmware commands in
`control/firmware/README.md`.

**Safety, every stage**
- Plug and unplug things (motors including the key motor cable, and drivers)
  only with **12 V off**.
- Keep a hand near the 12 V plug: pulling it stops everything. Typing `!`
  aborts a move.
- Power order: USB first, then 12 V. Off: 12 V first.
- Start at low current, and never put fingers in the gears.

**Software on the Mac** (set up once; details in `docs/manual.md` §3–4):
- **Arduino IDE 2** (arduino.cc) builds the firmware and uploads it over USB:
  board package **Arduino AVR Boards**, library **TMCStepper 0.7.3**, board
  **Arduino Mega or Mega 2560**, port `/dev/cu.usbmodemXXXX` (manual §3.2,
  §3.3, §4.1).
- **The logger** talks to the robot: you type commands in it, and it saves
  everything to `runs/<date>_raw.log` (for any stage you can just send me
  that file). Once: `python3 -m venv ~/safe-robot-venv` and
  `~/safe-robot-venv/bin/python -m pip install pyserial` (manual §3.5). Each
  time, from the repo folder:
  `~/safe-robot-venv/bin/python control/firmware/tools/logger.py --port /dev/cu.usbmodemXXXX`
  (`ls /dev/cu.usbmodem*` finds the port; manual §5.3).
- Or the IDE's Serial Monitor at 115200, "Newline" (it doesn't save). Only one
  program can have the port open: close the logger before uploading.

---

## Stage 0 — Preparation (no power)

1. **Flash** (manual §3.1–3.3 and §4.1): get the code (`git clone` or
   GitHub's Download ZIP), install the Arduino IDE, the AVR board package and
   TMCStepper 0.7.3. Open `control/firmware/safe_robot/safe_robot.ino`,
   board "Arduino Mega or Mega 2560", **Verify**, then **Upload** with only
   USB connected (RAMPS may be on or off the Mega).
2. Start the logger and type `status`. You should see
   `# Fichet safe robot 0.4 (2026-10-08, rev 2026-10-08.1) - type help` and `# state=IDLE run=0 next=0 ...`.
3. **RAMPS jumpers** (under the sockets): X none; Y **MS1** only; Z **MS2**
   only; **E0 MS1 + MS2** (the key, address 3); E1 none; **no MS3 jumper
   anywhere**. (Correction, 2026-10-09: E0 was missing from this step.)
4. **EN-end pins** on all **four** drivers (the three dials and the key;
   leave the spare untouched): before fitting the heatsinks, cut the
   **bottom** ends of the two EN-end pins flush underneath; leave the tops.
   No soldering (revision 2026-10-08.2; `control/wiring.md` §3.3).
5. **VREF pots**: set later, by measurement, in stage 1 (step 3a). (BTT's
   manual doesn't say which way is minimum, and the pot only has a voltage
   with 12 V on.)
6. Fit heatsinks. **Driver orientation**: do the multimeter check in manual
   §2.4 step 2: match the driver's EN and GND pins to the small EN and GND
   labels in the RAMPS silkscreen. The driver's VS/GND/motor side goes in the
   socket row nearer that axis's motor header.

**Send back**: the two lines from step 2; the orientation check results for
X (manual §2.4 step 2); any surprises in steps 3–6.

---

## Stage 1 — One driver talking over UART (no motor)

Setup: Mega + RAMPS, **one** driver in the **X** socket, no motor. UART
pigtail (manual §2.5, already checked with the multimeter): lead **TX2** on
AUX-4 pin 18, **RX2** on AUX-4 pin 17, **A** on the top of the X driver's
**RX** pin (4th from EN). Leads B, C and KEY hang free for now (their female
ends are insulated; keep them off the board). An F–F jumper from the top of
the X driver's **DIAG** pin → X_MIN **S** pin. 12 V into RAMPS's **5A** input.

1. USB on, logger running. Then 12 V on.
2. Type `set axes 1`, then `ping`.
3. Look at the `DRV,A,...` line. Good: `DRV,A,1,21,0,0,0,0,…` = present,
   version 21, MS1 = 0, MS2 = 0, DIAG pin low, DIAG register low. The last two
   fields are status (GSTAT reads 1 right after power-up: that's the
   driver's "I was reset" flag, normal).
3a. **Set its VREF pot to minimum by measurement** (12 V on; the driver stays
   off, EN held high by the RAMPS pull-up, and no motor is connected).
   Multimeter on DC V, black probe on the "5A" − terminal, red probe on the
   pot's metal centre. Turn the pot slowly, a little at a time, the way that
   makes the reading **fall**, until it stops falling (near 0 V). Which way
   that is isn't in BTT's manual, hence measuring. If the centre reads 0 V
   whichever way you turn, stop and tell me.
   **Careful: the pot sits right beside the VM (12 V, "VS" on the board) and
   GND pins.** Put heat shrink over the screwdriver's shaft so only the tip
   is bare, or use a plastic trimmer tool. (Paul, 2026-10-09: a bare
   screwdriver bridged VM–GND, a spark, and the pot then read 0 V: the 12 V
   rail had dropped out (RAMPS F1 or the PSU's protection). After 2 minutes
   with everything off it was back: 12.3 V at the "5A" terminal and at VM,
   all four drivers answering `ping`, no damage.)
4. If it says `DRV,A,0,0,...`: 12 V off. Check lead A is on **RX** (not TX
   or CLK), the TX2 and RX2 leads aren't swapped on AUX-4 (TX2 is the lead
   with R1), and there's no jumper on X's MS3 position. Then try again.
5. 12 V off. Add the Y, Z and **E0 (key)** drivers — with their jumpers and
   DIAG jumpers: Y → X_MAX S, Z → Z_MIN S, **E0 → Z_MAX S** — and pigtail
   leads B, C and KEY on the RX pins of the Y, Z and E0 drivers. 12 V on.
   `set axes 15`, `ping`. Then set the **Y, Z and E0 pots** to minimum the
   same way as step 3a.
6. **Check each DIAG lead lands on its own input** (the pull test). The 7th
   field of a `DRV` line is the level the Mega reads on that axis's DIAG
   input; its pull-up makes it 1 when nothing drives it. Pull the **A** lead
   off the top of the X driver's DIAG pin (leave the header end), `ping`:
   only `DRV,A` may show 1 there. Put it back; repeat for B (Y driver),
   C (Z driver) and K (E0 driver). Another axis going to 1 = crossed leads in
   the endstop connector; none = the lead isn't on a DIAG input. (Paul,
   2026-10-10: the A and K leads were crossed in the connector, which showed
   up only in stage 3 as a stall that never stopped the key; this step catches
   it before any motor turns.)

**Send back**: the `DRV,A` line from step 3; the lowest VREF reading and
which way you turned (step 3a; and for the other three); the four `DRV` lines from
step 5; for step 6, which axis went to 1 for each pulled lead. Expect `DRV,B,1,21,1,0,...`, `DRV,C,1,21,0,1,...`
and **`DRV,K,1,21,1,1,...`** (the key in E0, address 3: MS1 = MS2 = 1). If a
DIAG field reads 1 at rest, say which.

---

## Stage 2 — One motor turning at low current

Setup: as stage 1 end; a motor on the **X** motor header (12 V off while
plugging). The motor sits loose on the bench. Put a tape flag on its shaft and
draw a mark on the bench in line with it.

1. 12 V on. `set axes 1`, `set maA 400` (0.4 A).
2. `jog A 200`. The shaft should make **exactly one turn** and stop on the
   mark. Note which way it turned, seen from the shaft end.
3. `jog A -200`: one turn back.
4. `jog A 800` (4 turns): smooth? Back on the mark?
5. If it buzzes or jitters instead of turning, 12 V off and swap the two
   middle wires of the motor plug (`docs/bom.md` note). Then repeat.
   (Paul, 2026-10-09/10: needed on **all four** motors, every plug wired the
   same; after the swap they all run smooth and quiet.
   `control/harness/ramps_and_uart.md` A5.)

**Result (Paul, 2026-10-10):** `jog A 200` = exactly one turn, so the motor
is **1.8° per step (200 full steps/rev)**, as `config.h` assumes. `jog A 200`
turns the shaft **clockwise seen from the shaft end** (motor A, plug black
toward 2B, `invA` 0). What that means for the dial is settled in stage 4b.

**Send back**: (a) did 200 steps give exactly one turn — or how far off
(e.g. "half a turn" means the motor is 0.9°/step); (b) direction of `jog A
200`, seen from the shaft end (clockwise/anticlockwise); (c) smooth or noisy;
(d) the `# moved ...` lines.

---

## Stage 3 — StallGuard on the bench (by hand): check the 50 % rule

Same setup. The firmware calibrates its own stall thresholds: it measures
the free-running StallGuard reading, then calls it a stall when the reading
falls to **50 %** of that (`CFG_SG_CAL_PCT`). This stage checks that 50 %
sits clearly between running free and stalling. It follows the datasheet's
own procedure (§11.2): watch SG_RESULT running free, then while braking the
shaft by hand.

1. `set maA 1000` (the dial current), `set sgA 0` (no stopping).
2. `sg A 800`. The logger prints `SG,A,<step>,<value>` lines while the motor
   runs free. Note the typical and the lowest value.
3. `sg A 800` again. This time pinch the tape flag (or the shaft through a
   rag) with growing force until the motor stalls (it buzzes and stops
   turning). Let go at once. Note the lowest value just before the stall.
4. Check the rule: `set sgA <free-running median ÷ 4>` (that is how the
   firmware sets it, `sgthrsFromBaseline()`: SGTHRS = median × 50 % ÷ 2,
   and DIAG fires when SG_RESULT ≤ 2 × SGTHRS). **Correction (2026-10-10):**
   this said "lowest ÷ 4"; the firmware uses the median. `jog A 800` without touching, 3 times:
   each must end `stalled=0`. Then `jog A 800` and pinch, 3 times: each must
   stop by itself, `stalled=1`, soon after you load it.

**Send back**: the raw log (it has all the SG lines), and whether step 4
behaved. If 50 % is too tight or too loose, I'll change `CFG_SG_CAL_PCT`.

**Result, key motor (Paul, 2026-10-10).** Run on the key (`K`, E0) instead of
dial A: the dial motors were already in their housing, the key turner's
spindle was easy to reach, cap off the key. `set maK 600` (the key's start
current), 1 rev/s, 1/16 microsteps, StealthChop, 1 m motor cable.
- Running free (step 3's run outside the grip, 1,147 samples): SG_RESULT
  median **276**, lowest **248**, highest 350.
- Gripped: falls steadily while the shaft still turns (230 → 46), crossing
  the 50 % line (138) about 14 full steps before the shaft stopped; stalled,
  it swings 0–340 with readings of **0–20** about every 4 full steps.
- `set sgK 69` (276 × 50 % ÷ 2): 4 of 4 free runs `stalled=0` (800 full
  steps each); 3 of 3 gripped runs stopped by themselves, `stalled=1`, after
  156, 200 and 120 full steps.
- **The 50 % rule holds for the key** at 0.6 A through the 1 m cable, with a
  wide margin (lowest free 248 against a trip point of 138). The dials get the
  same check from their own calibration on the door (stage 4).
- On the way: the first try never stopped because the A and K DIAG leads were
  crossed in the endstop connector (found with the pull test, now stage 1
  step 6).

---

## Stage 4 — Dial unit on the door: seat, calibrate, home

**4a. By hand first (no electronics).** Already answered (Paul,
2026-10-06): every dial turns clockwise without limit, stops when turned
anticlockwise, and has 20 evenly spaced clicks (18°). There are no marks on
the door. The robot now finds the clicks itself. The dials turn with the real
key inserted at its start position, and still click with the key turned to
its ~100° stop (Paul, 2026-10-06). Nothing left to do by hand here.

**4b. On the door** (12 V off while placing): dial unit on, all three motors
plugged in (A = top-left = X, B = top-right = Y, C = bottom = Z). The key
turner is not needed yet. 12 V on. `set axes 7`.
1. **Direction**: `jog A 10`. Watch dial A's big gear, or a tape flag on it.
   Did the *dial* turn clockwise or anticlockwise, seen from in front of the
   safe? Same for `jog B 10` and `jog C 10`.
   (The dials stop anticlockwise, so the firmware homes anticlockwise and
   treats clockwise as positive. I'll set the invert flags from your answer,
   or use `set invA 1` etc.)
   **Result (Paul, 2026-10-10):** with invert 0, `jog A/B/C 10` turned every
   dial **anticlockwise**, all three alike, so `CFG_INVERT_A/B/C` = 1
   (firmware after this change; until it is uploaded, `set invA 1`,
   `set invB 1`, `set invC 1` after every reset).
   Don't look for a stall by jogging a dial into its stop: before
   `calibrate`, the dial thresholds are 0 (`CFG_SGTHRS_A/B/C`, StallGuard
   off), and a short jog is mostly ramp, below the speed where StallGuard
   reads (`CFG_SG_MIN_RPS` 0.4 rev/s) plus the first 2 full steps ignored.
   `calibrate` sets the thresholds and homes with bounded moves at speed.
   (Paul, 2026-10-10: short jogs into the stop didn't stop on a stall.)
2. **Seat**: `seat`. Each dial turns 1/8 turn slowly **clockwise** (the way it
   never meets its stop). Listen and watch: does each plug **drop into its
   star** (a click, the plug moves in)?
3. **Calibrate**: `calibrate`. For each dial, it makes one free clockwise
   turn and prints `CAL,…,A,<baseline>,<threshold>,<ripple>,<noise>,<clicks
   found 1/0>`. Then it homes (two `HOME` lines; pass 2 should read about
   **40**) and prints `OFFSET,…,A,<position 1 in full steps>,1`.
   - `stalled on its free calibration turn`: `set sgA 0` (and B, C), then
     retry.
   - `clicks not clear`: send me the log; it falls back to a fixed offset.
4. **Home repeatability**: `home A` 5 times, then B and C. Pass 2 should stay
   near 40 each time.
5. **Parked on a click?** `goto 5 5 5`, then `release` (motors off). Watch and
   listen: does any dial **snap** to a click when released? Sitting still
   means it was parked on its click.
6. **Key out vs. key in.** `release`, take the real key out, then
   `calibrate`. Put the key back in at its start, then `calibrate` again.
   This compares the dials' load and click pattern with and without the
   key. A clear difference would suggest the key changes what the dials
   drive (`control/sequence.md`, "Does a combination dialled with the key
   already in count?"). The same numbers are only weak reassurance.

**Send back**: directions; seated yes/no per dial; the raw log
(CAL / HOME / OFFSET lines); for 4b.5, which dials snapped, if any; for
4b.6, both runs' CAL and OFFSET lines, labelled "key out" and "key in".

---

## Stage 5 — Key turner: direction, current, stop angle

**5a. By hand**: all answered (Paul, 2026-10-06). The key goes in one way
only. From there it won't turn anticlockwise at all: that rest stop is the
firmware's key home. It turns ~100° clockwise to its stop and stays wherever
it is left (no spring back). It comes out only back at the start. So before
any stage below, turn it back to the start by hand.

**5b. Mounted**: key in, at its start; key turner on (12 V off while placing
and plugging). The key driver is in the RAMPS **E0** socket (revision
2026-10-08.1), VREF pot at minimum; its motor's own cable is plugged into the
E0 motor header. 12 V on. `set axes 8` (key only), then `ping`: expect
`DRV,K,1,21,1,1,...`.
1. **Direction**: `set maK 400`, `key 10`. The key should turn **clockwise**
   10° and come back. If it went anticlockwise: `set invK 1`, and say so.
2. **Minimum current**, with StallGuard off (`set sgK 0`): `key 80` at
   `set maK 500`, then 400, 300, 250, 200. For each, did the key actually get
   to about 80° (watch the cap), or did the motor skip or buzz?
3. Set `maK` to **2 × the lowest current that worked**, 1000 at most.
4. **Calibrate the key**: `calibrate`. It turns the key 60° clockwise, sets
   the key's threshold from its free-running reading (`CAL,…,K,…`), then turns
   back until it stalls on the rest stop. That return proves the threshold
   works. If it says `did not find its rest stop`: send me the log.
5. **Stop angle**: `learn`, 3 times. Each prints 3 `LEARN` lines and an
   `NSTOP` line (N and the spread).
6. Watch the key-turner housing during the learns: does it shift or rock
   on its magnets?
7. **Key StallGuard through the cable**: during the `learn` turns, did the
   key's stall detection find the stop cleanly (an `NSTOP` line each time,
   with a small spread)? If it reads dull or erratic, shorten the key motor
   cable and repeat (revision 2026-10-08.1: the cable length is the one thing
   about the E0 move still unproven).

**Send back**: direction; the current table from 5b.2; final `maK`; the raw
log (CAL, LEARN, NSTOP lines); any housing movement; whether the key's
StallGuard found the stop cleanly through the 1 m cable.

---

## Stage 6 — A short dry run

Everything on the door, both units, cable plugged. I'll have sent a
`config.h` with your numbers by now; upload it. 12 V on.

1. `cfg`, then `ping`: all four `DRV` lines present.
2. `reset yes`, then `start`. The session start takes ~40 s: key home, key
   calibration, seat, one calibration turn per dial, home ×3, learn.
3. Let it run **~50 attempts** (about a minute). Each attempt turns one dial
   by one click, turns the key to its stop and back.
4. Press the **button** (or type `pause`). It finishes the attempt, re-checks
   (re-homes and re-learns), and stops.
5. Watch for: anything sliding on the door; a dial moving while the key is
   turned (it never should); odd noises.
6. **Power-dip check** (does the firmware notice a driver reset? See
   `control/firmware/README.md`, "Driver resets"):
   1. `home`. It homes the key, then each dial. Wait until nothing moves.
   2. Switch the 12 V supply off, count to 5, and switch it back on. Leave
      the USB connected.
   3. Straight away, `goto 2 2 2`. Expect `GSTAT,…,A,1,before`, then
      `ERR,…,DRVFAULT,…`. **No dial should move.** If the boot line
      `# Fichet safe robot …` appeared when the 12 V came back, the Mega
      restarted instead: say so.
   4. `ping`. In each of the four `DRV` lines, the second-to-last field
      (GSTAT) should read `1`. The paused run is untouched.

**Send back**: the raw log; the time for 50 attempts; anything that moved or
sounded wrong; from step 6, the `GSTAT`, `ERR` and `DRV` lines, and whether
anything moved after `goto`. Then we'll set the classification bands from the
measured spread and start the real run with `resume`.

---

## What these stages settle (`config.h` / `CLAUDE.md` open items)

| Open item | Stage |
|---|---|
| Driver UART addresses and wiring (UART lead on each driver's RX pin) | 1 |
| Motor step angle | 2: **1.8° confirmed** (Paul, 2026-10-10) |
| StallGuard thresholds — now self-calibrated; the 50 % rule and speeds | 3, 4, 5 |
| Hard stop and clicks per turn | answered 2026-10-06: stop anticlockwise, unlimited clockwise, 20 clicks |
| Dials still turn with the key inserted at rest | answered 2026-10-06: yes, at rest and at the key's ~100° stop |
| Does a combination dialled with the key in count? | weak hint from 4b.6; the real test is the first full run |
| Motor direction ↔ dial direction | 4b |
| Plug seating (seat routine angle and speed) | 4b |
| Position 1 relative to the stop — now found from the clicks; parked-on-click check | 4b |
| Key motor direction | 5 (rest stop answered 2026-10-06: none anticlockwise of the start → `keyhome` 0) |
| Key current (2 × minimum) | 5 |
| Key stop angle N and its spread (classification bands) | 5, 6 |
| Magnets holding under real loads | 5, 6 |
| The firmware notices a driver reset (GSTAT check, v0.3) | 6 |
| Dial torque (dial current, still 1 A) | not measured directly: if homing works at 1 A with margin, keep it; we can try 0.8 A in stage 4 |

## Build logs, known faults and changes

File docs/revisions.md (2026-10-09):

# Project revisions

> **Revision 2026-10-09.1** · this file is the revision log · current ID in `REVISION`

Every project document and drawing carries the project revision it was last
brought up to date in, so a printed or downloaded copy can be told apart from
a newer one. The ID is the date plus a sequence number for that day:
`2026-10-08.1` is the first revision of 8 October 2026.

**Rules (for Paul and for any Claude session):**
- The current ID lives in one place: the `REVISION` file at the repo root.
- A design change that affects how the robot is built, wired or run gets a
  new ID. Bump `REVISION`, add an entry below, and update the revision line
  in every document (`python3 tools/check_revision.py` lists any that don't
  match). Typo fixes and notes don't need a new ID.
- Markdown documents carry the line near the top:
  `> **Revision 2026-10-08.1** · …`. Generated drawings (schematic PDF,
  harness, overview, UART pigtail) print it in their title block, read from
  `REVISION` when they're regenerated.
- The firmware has its own version (`FW_VERSION` in `safe_robot.ino`),
  which also names the project revision it was built for.

## Log (most recent first)

### 2026-10-09.1 — start/stop button mount on the electronics deck

**Change.** The 7mm start/stop button gets a place on the electronics deck
(Paul's design, 2026-10-09): a 7.4mm hole with a 10 x 2.5mm recess in the
deck's underside for the switch body, left of the Mega next to the deck leg
that the base plate doesn't cover; and a 4mm wire hole beside the RAMPS
endstop block, with a small lobe added to the deck outline around it.
Reasoning and checks: `docs/housing_decisions.md`, 2026-10-09.

**Also recorded** (build notes, no design change): the endstop block's
connector is one 3-row x 6 female block (three glued 6-pin strips): S row
DIAG A, DIAG B, button, (empty), DIAG C, DIAG key; the button's GND under
Y_MIN. Paul's idea of moving the DIAG leads to the X and Y headers was
checked and **not** taken: D14/D15 have no external interrupt, and the
pin-change interrupt they do have clashes with Arduino's SoftwareSerial,
which TMCStepper links in (build fails: "multiple definition of
`__vector_10`").

**Reprint:** `cad/electronics_deck.stl`.

**Not changed:** wiring, pin map, firmware (still v0.4).

**Documents updated:** `cad/dial_unit_housing.scad` (+ STLs),
`cad/tools/button_mount_check.py` (new), `docs/housing_decisions.md`,
`docs/manual.md` (1.4, 1.7, print table, 2.7), the RAMPS bench sheet,
`docs/bom.md`, `CLAUDE.md`, the drawing title blocks, and the revision
line of every document.

**Previous state:** `main` at `26d4e3b` plus PR #30 (revision 2026-10-08.2).

### 2026-10-08.2 — UART pigtail replaces the hub board

**Change.** After 2026-10-08.1 the hub board held only R1 (1 kΩ) and the UART
bus node. It becomes a small harness instead (Paul: "more like a custom cable
than a full daughter board"): the **UART pigtail**, six leads with female
Dupont ends (TX2, RX2, A, B, C, KEY), R1 in line in the TX2 lead, all joined
in one solder splice that zip-ties to the deck. Same circuit (TMC2209 DS
Fig. 4.1). Reasoning: `control/wiring.md`, log 2026-10-08 (pigtail).

**Gone:** the hub perfboard and its male header pins. The same six F–F
jumpers are used, cut, with their hub ends soldered into one splice (six
fewer plug-in joints). The hub's place on the deck is no longer a mechanical
to-do.

**Changed:**
- TX2 / RX2 pigtail leads go straight onto AUX-4 pins 18 / 17; leads A, B,
  C, KEY onto the X, Y, Z, E0 MS3 jumper pins (signal side), as before.
- New build step with a multimeter check (manual §2.5).
- `control/harness/hub_board.*` → `uart_pigtail.*`;
  `control/harness/ramps_and_hub.md` → `ramps_and_uart.md`.
- Schematic sheet 1: the 12 V line now goes to the RAMPS block
  (**Correction**: in 2026-10-08.1 it was drawn into the hub block).
- Manual fault table (GSTAT 1 / 80 for the key): the stale "hub fuse"
  advice from before 2026-10-08.1 is replaced.

**Also in 2026-10-08.2 (later the same day, before the PR merged): taps on
the drivers, no soldering.** Paul's BTT V1.3s have RX/TX/CLK as tall pins
through the top, and the two EN-end pins go through the board. Measured:
RX–TX open (R10 not fitted); a Dupont grips the top of RX and conducts.
- Pigtail leads A, B, C, KEY clip onto the **top of each driver's RX pin**,
  not the RAMPS MS3 jumper pin (whose clearance under a seated driver was
  never checked). MS3 jumper still off.
- **DIAG mod → two snips**: cut both EN-end pins' bottom ends flush; DIAG is
  a plain F–F jumper on the top of the DIAG pin (next to the pot). No
  soldering on the drivers; no cut-in-half jumpers.
- **Driver orientation** (manual §2.4 step 2): no square pad on top, but
  small EN and GND silkscreen labels at each socket (Paul used them,
  2026-10-08). The VS/GND/motor row goes nearer the motor header; a
  continuity check to the "5A" terminal is the cross-check.
- Schematic sheets 3–7, the pigtail drawing, harness and overview, the
  bench sheet, manual §2.3/2.4/2.5/2.7, bring-up stages 0–1, `CLAUDE.md`,
  `docs/bom.md` and two firmware comments updated. Reasoning:
  `control/wiring.md`, log 2026-10-08 (evening).

**Not changed:** firmware (still v0.4; its boot line names rev
2026-10-08.1, the revision it was built for, and it runs unchanged), pin map,
addresses, currents, power order.

**Documents updated:** `control/wiring.md`, `control/harness/*` (schematic,
harness, overview, pigtail drawing, bench sheet), `control/bringup.md`
(stage 1), `docs/manual.md`, `docs/bom.md`, `CLAUDE.md`, `control/README.md`,
`tools/check_revision.py`, and the revision line of every document.

**Previous state:** `main` at commit `b5c4124` (revision 2026-10-08.1).

### 2026-10-08.1 — key driver moves onto the RAMPS (E0 socket)

**Change.** The key turner's TMC2209 moves from its own perfboard at the key
turner to the RAMPS **E0** socket, beside the three dial drivers (Paul's
suggestion; analysis in `control/wiring.md`, log 2026-10-08). The key motor's
own ~1 m cable plugs into the E0 motor header.

**Gone:** the remote driver board, the 6-conductor inter-unit cable and its
Phoenix connectors, the 12 V branch on the hub board with its fuse (PTC, or
the interim 1.6 A glass fuse and its printed holder), and the remote board's
two 100 µF capacitors.

**Changed:**
- Key pins: STEP D26, DIR D28, EN D24 (E0 socket); DIAG D19 (Z_MAX) as
  before, now through the E0 driver's own DIAG-mod lead. Address 3 = MS1 +
  MS2 jumpers under E0.
- DIAG mod on **four** drivers, not three.
- The hub board shrinks to the UART junction: R1 (1 kΩ) and the bus node.
  12 V goes from the PSU adapter straight into the RAMPS "5A" terminal.
- Firmware v0.4: the key is an ordinary axis (DIR and EN pins); the UART
  direction workaround is gone; the key driver now stays off at power-up.

**Documents updated:** `control/wiring.md`, `control/harness/*` (schematic,
harness, overview, hub board, RAMPS/hub sheet), `control/sequence.md`,
`control/bringup.md`, `control/firmware/` (code, tests, README),
`docs/manual.md`, `docs/bom.md`, `docs/order_remaining_parts.md`,
`CLAUDE.md`, `README.md`, `control/README.md`. Every document now carries
this revision line.

**Previous state:** `main` at commit `76a4167` (2026-10-07), before this
revision. There were no revision IDs before this one.

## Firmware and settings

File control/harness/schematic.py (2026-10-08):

#!/usr/bin/env python3
"""Wiring schematic of the Fichet safe robot -> control/harness/schematic.pdf

A4 landscape, colour. Revision in each title block (from the REVISION file). Every connection is from control/wiring.md
(harness v1); where the two ever differ, wiring.md wins. RAMPS-internal
parts (F1, D1, pull-ups) are from the RAMPS 1.4 KiCad port's netlist.

No text is drawn below MIN_PT (8 pt), so the printed sheets stay legible:
Sheet.setfont() refuses anything smaller.

    python3 -m pip install reportlab        # once
    python3 control/harness/schematic.py    # writes control/harness/schematic.pdf
"""
import os
import sys

from reportlab.lib.colors import HexColor
from reportlab.lib.pagesizes import A4, landscape
from reportlab.pdfbase import pdfmetrics
from reportlab.pdfbase.ttfonts import TTFont
from reportlab.pdfgen import canvas

W, H = landscape(A4)          # 841.9 x 595.3 pt
MIN_PT = 8
DATE = "2026-10-08"
# project revision, from the REVISION file at the repo root
REV = open(os.path.join(os.path.dirname(os.path.dirname(os.path.dirname(os.path.abspath(__file__)))), "REVISION")).read().strip()
BOTTOM = H - 82               # content above this; legend + title block below

# ---------------------------------------------------------------- fonts
# Liberation Sans (Arial metrics; has Ω µ → ×). Arial on a Mac works too.
FONT_CANDIDATES = [
    ("/usr/share/fonts/truetype/liberation/LiberationSans-Regular.ttf",
     "/usr/share/fonts/truetype/liberation/LiberationSans-Bold.ttf"),
    ("/System/Library/Fonts/Supplemental/Arial.ttf",
     "/System/Library/Fonts/Supplemental/Arial Bold.ttf"),
    ("/usr/share/fonts/truetype/dejavu/DejaVuSans.ttf",
     "/usr/share/fonts/truetype/dejavu/DejaVuSans-Bold.ttf"),
]
for _reg, _bold in FONT_CANDIDATES:
    if os.path.exists(_reg) and os.path.exists(_bold):
        pdfmetrics.registerFont(TTFont("F", _reg))
        pdfmetrics.registerFont(TTFont("FB", _bold))
        break
else:
    sys.exit("no usable TrueType font found (see FONT_CANDIDATES)")

# ---------------------------------------------------------------- colours
INK = "#1A1A1A"
GREY = "#666666"
WARN = "#C62828"
NETS = {   # net class: (colour, line width)
    "12V":   ("#C62828", 1.8),
    "5V":    ("#E67E00", 1.6),
    "GND":   ("#1A1A1A", 1.4),
    "UART":  ("#1B8A3A", 1.5),
    "CTRL":  ("#1F4FB4", 1.3),   # STEP / DIR / EN, button
    "DIAG":  ("#8E3FB0", 1.4),
    "MOTOR": ("#8A5A1E", 1.5),
    "TIE":   ("#666666", 1.1),   # jumpers, ties, spare
}
NET_NAMES = [("12V", "+12 V"), ("5V", "+5 V (logic, VIO)"), ("GND", "GND"), ("UART", "UART bus"),
             ("CTRL", "STEP / DIR / EN, button"), ("DIAG", "DIAG (stall)"), ("MOTOR", "motor coils"),
             ("TIE", "jumper / tie / spare")]
FILL = {"module": "#E8EEF6", "build": "#FFF4CC", "ref": "#EFEFEF"}


class Sheet:
    """One A4 landscape page. Coordinates are points from the TOP-left corner."""

    def __init__(self, c, no, total, title, note=None):
        self.c, self.no, self.total, self.title = c, no, total, title
        self.frame(note)

    # ------------------------------------------------------------ basics
    def Y(self, y):
        return H - y

    def setfont(self, size, bold=False):
        if size < MIN_PT:
            raise ValueError(f"text below {MIN_PT} pt on sheet {self.no}")
        self.c.setFont("FB" if bold else "F", size)

    @staticmethod
    def tw(s, size=8, bold=False):
        return pdfmetrics.stringWidth(s, "FB" if bold else "F", size)

    def text(self, x, y, s, size=8, bold=False, color=INK, anchor="l"):
        """y is the text baseline."""
        c = self.c
        self.setfont(size, bold)
        c.setFillColor(HexColor(color))
        {"l": c.drawString, "c": c.drawCentredString, "r": c.drawRightString}[anchor](x, self.Y(y), s)

    def para(self, x, y, rows, size=8, color=INK, lead=None, anchor="l"):
        """rows: str, or (str, bold), or (str, bold, colour)."""
        lead = lead or round(size * 1.3, 1)
        for i, r in enumerate(rows):
            r = (r,) if isinstance(r, str) else r
            self.text(x, y + i * lead, r[0], size, r[1] if len(r) > 1 else False,
                      r[2] if len(r) > 2 else color, anchor)
        return y + len(rows) * lead

    def line(self, pts, color=INK, w=1.0, dash=None):
        c = self.c
        p = c.beginPath()
        p.moveTo(pts[0][0], self.Y(pts[0][1]))
        for x, y in pts[1:]:
            p.lineTo(x, self.Y(y))
        c.setStrokeColor(HexColor(color))
        c.setLineWidth(w)
        c.setDash(dash or [])
        c.setLineCap(1)
        c.setLineJoin(1)
        c.drawPath(p, stroke=1, fill=0)
        c.setDash([])

    def wire(self, pts, net):
        col, w = NETS[net]
        self.line(pts, col, w)

    def hwire_hop(self, x1, x2, y, hops, net):
        """Horizontal wire x1 -> x2 (x1 < x2) with a hop over each x in hops."""
        col, w = NETS[net]
        c, r = self.c, 4.5
        p = c.beginPath()
        p.moveTo(x1, self.Y(y))
        for hx in sorted(hops):
            p.lineTo(hx - r, self.Y(y))
            p.arcTo(hx - r, self.Y(y) - r, hx + r, self.Y(y) + r, startAng=180, extent=-180)
        p.lineTo(x2, self.Y(y))
        c.setStrokeColor(HexColor(col))
        c.setLineWidth(w)
        c.setLineCap(1)
        c.drawPath(p, stroke=1, fill=0)

    def vwire_hop(self, x, y1, y2, hops, net):
        """Vertical wire y1 -> y2 (y1 < y2, top to bottom) with a hop at each y in hops."""
        col, w = NETS[net]
        c, r = self.c, 4.5
        p = c.beginPath()
        p.moveTo(x, self.Y(y1))
        for hy in sorted(hops):
            p.lineTo(x, self.Y(hy - r))
            p.arcTo(x - r, self.Y(hy) - r, x + r, self.Y(hy) + r, startAng=90, extent=-180)
        p.lineTo(x, self.Y(y2))
        c.setStrokeColor(HexColor(col))
        c.setLineWidth(w)
        c.setLineCap(1)
        c.drawPath(p, stroke=1, fill=0)

    def dot(self, x, y, net):
        self.c.setFillColor(HexColor(NETS[net][0]))
        self.c.circle(x, self.Y(y), 2.7, stroke=0, fill=1)

    def rect(self, x, y, w, h, stroke=INK, fill=None, lw=1.0, dash=None, r=0):
        c = self.c
        c.setStrokeColor(HexColor(stroke))
        c.setLineWidth(lw)
        c.setDash(dash or [])
        if fill:
            c.setFillColor(HexColor(fill))
        if r:
            c.roundRect(x, self.Y(y + h), w, h, r, stroke=1, fill=1 if fill else 0)
        else:
            c.rect(x, self.Y(y + h), w, h, stroke=1, fill=1 if fill else 0)
        c.setDash([])

    def poly(self, pts, stroke=INK, fill=None, lw=1.0):
        c = self.c
        p = c.beginPath()
        p.moveTo(pts[0][0], self.Y(pts[0][1]))
        for x, y in pts[1:]:
            p.lineTo(x, self.Y(y))
        p.close()
        c.setStrokeColor(HexColor(stroke))
        c.setLineWidth(lw)
        if fill:
            c.setFillColor(HexColor(fill))
        c.drawPath(p, stroke=1, fill=1 if fill else 0)

    def circle(self, x, y, r, stroke=INK, fill=None, lw=1.2):
        c = self.c
        c.setStrokeColor(HexColor(stroke))
        c.setLineWidth(lw)
        if fill:
            c.setFillColor(HexColor(fill))
        c.circle(x, self.Y(y), r, stroke=1, fill=1 if fill else 0)

    # ------------------------------------------------------------ frame, legend
    def frame(self, note):
        self.rect(14, 14, W - 28, H - 28, lw=1.2)
        self.text(24, 36, self.title, 15, True)
        if note:
            self.text(24, 52, note, 9, color=GREY)
        bx, by, bw, bh = W - 290, H - 76, 276, 62
        self.rect(bx, by, bw, bh, lw=1.0, fill="#FFFFFF")
        self.line([(bx, by + 20), (bx + bw, by + 20)], INK, 0.6)
        self.line([(bx, by + 41), (bx + bw, by + 41)], INK, 0.6)
        self.text(bx + 6, by + 14, "Fichet safe robot — wiring schematic", 9, True)
        self.text(bx + bw - 6, by + 14, f"Sheet {self.no} of {self.total}", 9, True, anchor="r")
        self.text(bx + 6, by + 35, self.title, 9)
        self.text(bx + 6, by + 56, f"{DATE} · revision {REV} · from control/wiring.md", 8, color=GREY)
        # legend: three rows, left of the title block
        x0, y = 24, H - 58
        rows = [NET_NAMES[:4], NET_NAMES[4:]]
        for row in rows:
            cx = x0
            for key, name in row:
                col, w = NETS[key]
                self.line([(cx, y - 3), (cx + 18, y - 3)], col, w + 0.8)
                self.text(cx + 22, y, name, 8)
                cx += 22 + self.tw(name) + 14
            y += 13
        cx = x0
        for key, name in [("module", "bought module"), ("build", "board you build"),
                          ("ref", "already on the RAMPS / Mega: nothing to buy")]:
            self.rect(cx, y - 8, 18, 9, stroke=GREY, fill=FILL[key], lw=0.6)
            self.text(cx + 22, y, name, 8)
            cx += 22 + self.tw(name) + 14

    # ------------------------------------------------------------ building blocks
    def board(self, x, y, w, h, label, kind="build", sub=None):
        self.rect(x, y, w, h, stroke=GREY, fill=FILL[kind], lw=0.9,
                  dash=None if kind == "module" else [4, 2], r=4)
        self.text(x + 7, y + 13, label, 9, True)
        if sub:
            self.text(x + 7, y + 24, sub, 8, color=GREY)

    def ic(self, x, y, w, left=(), right=(), pitch=21, pad=13, stub=10, fill="#FFFFFF"):
        """Box with pins. left/right: lists of (key, label) or None for an empty row.
        Returns ({key: (x, y) of the pin's outer end}, box height)."""
        n = max(len(left), len(right), 1)
        h = 2 * pad + (n - 1) * pitch
        self.rect(x, y, w, h, fill=fill, lw=1.3)
        pins = {}
        for side, items in (("l", left), ("r", right)):
            for i, p in enumerate(items):
                if not p:
                    continue
                py = y + pad + i * pitch
                if side == "l":
                    self.line([(x - stub, py), (x, py)], INK, 1.0)
                    self.text(x + 4, py + 3, p[1], 8)
                    pins[p[0]] = (x - stub, py)
                else:
                    self.line([(x + w, py), (x + w + stub, py)], INK, 1.0)
                    self.text(x + w - 4, py + 3, p[1], 8, anchor="r")
                    pins[p[0]] = (x + w + stub, py)
        return pins, h

    def conn(self, x, y, labels, side="l", pitch=20, pad=10, w=20, stub=6, fill="#FFFFFF"):
        """Connector: one box, one row per pin, labels[i] written inside.
        side 'l', 'r' or 'lr': where the stubs are. Returns {(label, side): (x, y)}."""
        n = len(labels)
        h = 2 * pad + (n - 1) * pitch
        self.rect(x, y, w, h, fill=fill, lw=1.3)
        pins = {}
        for i, lab in enumerate(labels):
            py = y + pad + i * pitch
            self.text(x + w / 2, py + 3, lab, 8, True, anchor="c")
            if "l" in side:
                self.line([(x - stub, py), (x, py)], INK, 1.0)
                pins[(lab, "l")] = (x - stub, py)
            if "r" in side:
                self.line([(x + w, py), (x + w + stub, py)], INK, 1.0)
                pins[(lab, "r")] = (x + w + stub, py)
        return pins, h

    # ------------------------------------------------------------ symbols
    def gnd(self, x, y):
        col = NETS["GND"][0]
        self.line([(x, y), (x, y + 6)], col, 1.4)
        for i, half in enumerate((7, 4.5, 2)):
            self.line([(x - half, y + 6 + i * 3), (x + half, y + 6 + i * 3)], col, 1.4)

    def flag(self, x, y, label, net, up=True):
        """Power flag on a vertical lead: bar + label above (up) or below."""
        col = NETS[net][0]
        d = -1 if up else 1
        self.line([(x, y), (x, y + d * 8)], col, NETS[net][1])
        self.line([(x - 6, y + d * 8), (x + 6, y + d * 8)], col, 1.8)
        self.text(x, y + d * 8 + (-4 if up else 11), label, 8, True, col, anchor="c")

    def tag(self, x, y, label, net, side="r"):
        """Net label in a rounded box attached at (x, y): side 'r' extends right, 'l' left."""
        col = NETS[net][0]
        tw = self.tw(label, 8, True) + 8
        bx = x if side == "r" else x - tw
        self.rect(bx, y - 6.5, tw, 13, stroke=col, fill="#FFFFFF", lw=1.0, r=3)
        self.text(bx + tw / 2, y + 3, label, 8, True, col, anchor="c")
        return bx + tw if side == "r" else bx

    def offpage(self, x, y, label, net, side="r"):
        """Off-sheet connector (arrow shape) attached at (x, y), pointing away."""
        col = NETS[net][0]
        tw = self.tw(label, 8) + 10
        h = 13
        if side == "r":
            pts = [(x, y - h / 2), (x + tw, y - h / 2), (x + tw + 7, y), (x + tw, y + h / 2), (x, y + h / 2)]
            tx = x + 5
        else:
            pts = [(x, y - h / 2), (x - tw, y - h / 2), (x - tw - 7, y), (x - tw, y + h / 2), (x, y + h / 2)]
            tx = x - tw + 5
        self.poly(pts, stroke=col, fill="#FFFFFF", lw=1.0)
        self.text(tx, y + 3, label, 8, False, col)
        return x + tw + 7 if side == "r" else x - tw - 7

    def nc(self, x, y):
        self.line([(x - 3.5, y - 3.5), (x + 3.5, y + 3.5)], GREY, 1.2)
        self.line([(x - 3.5, y + 3.5), (x + 3.5, y - 3.5)], GREY, 1.2)

    def res_h(self, x1, x2, y, net, label, above=True, lift=8):
        """IEC resistor on a horizontal wire (x1 < x2)."""
        xm = (x1 + x2) / 2
        self.wire([(x1, y), (xm - 12, y)], net)
        self.wire([(xm + 12, y), (x2, y)], net)
        self.rect(xm - 12, y - 4.5, 24, 9, fill="#FFFFFF", lw=1.3)
        self.text(xm, y - lift if above else y + 16, label, 8, True, anchor="c")

    def res_v(self, x, y1, y2, net, label, left=True):
        """IEC resistor on a vertical wire (y1 < y2)."""
        ym = (y1 + y2) / 2
        self.wire([(x, y1), (x, ym - 12)], net)
        self.wire([(x, ym + 12), (x, y2)], net)
        self.rect(x - 4.5, ym - 12, 9, 24, fill="#FFFFFF", lw=1.3)
        self.text(x - 9 if left else x + 9, ym + 3, label, 8, True, anchor="r" if left else "l")

    def ptc_h(self, x1, x2, y, label, net="12V"):
        """Resettable fuse (PTC) on a horizontal wire."""
        self.res_h(x1, x2, y, net, label, lift=13)
        xm = (x1 + x2) / 2
        self.line([(xm - 16, y + 8), (xm - 10, y + 8), (xm + 12, y - 8)], INK, 1.0)

    def cap_v(self, x, y1, y2, label_rows, side=1):
        """Polarised capacitor, vertical, + at the top: 12 V above, GND below."""
        ym = (y1 + y2) / 2
        self.wire([(x, y1), (x, ym - 3)], "12V")
        self.wire([(x, ym + 3), (x, y2)], "GND")
        self.line([(x - 8, ym - 3), (x + 8, ym - 3)], INK, 1.8)
        self.rect(x - 8, ym + 2, 16, 2.6, stroke=INK, fill=INK, lw=0.6)
        self.text(x - 11, ym - 5, "+", 8, True, anchor="c")
        self.para(x + 13 if side > 0 else x - 13, ym - 1, label_rows, 8, anchor="l" if side > 0 else "r")

    def diode_v(self, x, y1, y2, label_rows):
        """Diode on a vertical wire, anode at the top (y1), cathode at the bottom."""
        ym = (y1 + y2) / 2
        self.wire([(x, y1), (x, ym - 6)], "12V")
        self.wire([(x, ym + 6), (x, y2)], "12V")
        self.poly([(x - 7, ym - 6), (x + 7, ym - 6), (x, ym + 6)], stroke=INK, fill=INK)
        self.line([(x - 7, ym + 6), (x + 7, ym + 6)], INK, 1.8)
        self.para(x - 12, ym - 1, label_rows, 8, anchor="r")

    def button_v(self, x, y1, y2, label_rows):
        """Normally open push button on a vertical wire, signal at the top, GND at the bottom."""
        ym = (y1 + y2) / 2
        self.wire([(x, y1), (x, ym - 9)], "CTRL")
        self.wire([(x, ym + 9), (x, y2)], "GND")
        self.circle(x, ym - 9, 1.8)
        self.circle(x, ym + 9, 1.8)
        self.line([(x + 6, ym - 11), (x + 6, ym + 11)], INK, 1.5)
        self.line([(x + 6, ym), (x + 13, ym)], INK, 1.5)
        self.line([(x + 13, ym - 4), (x + 13, ym + 4)], INK, 1.5)
        self.para(x + 19, ym - 1, label_rows, 8)

    @staticmethod
    def motor_r(leads):
        return max(20, (max(leads) - min(leads)) / 2 + 4)

    def motor(self, cx, cy, leads, x_in, rows):
        """2-phase stepper: circle with M; the 4 leads come in from x_in at y = leads
        and end on the circle (its radius is set so all four reach it)."""
        r = self.motor_r(leads)
        for py in leads:
            dy = py - cy
            self.wire([(x_in, py), (cx - (r * r - dy * dy) ** 0.5, py)], "MOTOR")
        self.circle(cx, cy, r, fill="#FFFFFF", lw=1.5)
        self.text(cx, cy + 5, "M", 14, True, anchor="c")
        self.para(cx, cy + r + 13, rows, 8, anchor="c")

    def jumper(self, x, y, fitted):
        """RAMPS jumper pair seen as a symbol: signal pad at x (right), +5 V pad to its left."""
        self.rect(x - 3, y - 3, 6, 6, fill="#FFFFFF", lw=1.0)
        self.rect(x - 15, y - 3, 6, 6, fill="#FFFFFF", lw=1.0)
        if fitted:
            self.rect(x - 17, y - 5, 22, 10, stroke=INK, lw=1.8, r=2)
        self.wire([(x - 15, y), (x - 21, y)], "5V")
        self.text(x - 23, y + 3, "+5 V", 8, True, NETS["5V"][0], anchor="r")


# ====================================================================== sheet 1
def sheet_overview(s):
    blue = "#4F72A8"
    s.rect(138, 72, 486, 318, stroke=blue, lw=1.5, dash=[6, 3], r=6)
    s.text(146, 87, "DIAL UNIT  (on the door, over the 3 dial holes) — all the electronics", 9, True, blue)
    s.rect(640, 72, 180, 318, stroke=blue, lw=1.5, dash=[6, 3], r=6)
    s.text(650, 87, "KEY TURNER  (over the key)", 9, True, blue)

    def blk(x, y, w, h, title, rows, kind="module"):
        s.rect(x, y, w, h, stroke=INK, fill=FILL[kind], lw=1.1, r=3)
        s.text(x + 6, y + 14, title, 9, True)
        s.para(x + 6, y + 27, rows, 8)

    blk(20, 100, 96, 58, "Mac (USB)", ["logger.py, Arduino IDE", "USB-C -> USB-B"], "ref")
    blk(20, 286, 96, 70, "Power supply", ["Ledmo HTY-1200500", "12 V, 5 A max", "5.5 x 2.1 mm, centre +"], "ref")
    blk(150, 98, 142, 64, "Arduino Mega 2560 R3", ["the controller", "sheets 2, 6"])
    blk(150, 178, 142, 108, "RAMPS 1.4 (on the Mega)", ["X, Y, Z, E0 driver sockets", "endstop + AUX-4 headers",
                                                        "5 A input fuse feeds all 4", "D1 -> Mega VIN",
                                                        "sheets 2, 3, 4, 6"])
    blk(316, 98, 136, 196, "Drivers x 4", ["BTT TMC2209 V1.3", "in RAMPS X, Y, Z, E0", "",
                                            "X = dial A (top-left)", "Y = dial B (top-right)",
                                            "Z = dial C (bottom)", "E0 = key", "",
                                            "UART addresses 0,1,2,3", "taps on top (RX, DIAG)",
                                            "sheets 3, 4"])
    blk(468, 98, 140, 196, "Motors x 4", ["17HE19-2004S", "plug into the RAMPS", "motor headers", "",
                                           "A,B,C: dial plugs,", "14T -> 28T gears", "",
                                           "key: on the key axis", "", "sheets 3, 4"])
    blk(150, 306, 294, 70, "UART pigtail (you build)", ["six leads, one solder splice (rev 2026-10-08.2):",
                                                      "R1 1 kOhm in line in the TX2 lead; the splice is",
                                                      "the bus node where RX2 + all 4 PDN_UART meet",
                                                      "sheet 6"], "build")
    blk(648, 150, 164, 90, "Key motor", ["17HE19-2004S", "on the key axis", "", "its own ~1 m cable",
                                          "-> RAMPS E0 motor header", "sheet 4"])

    def lab(x, y, t, net):
        s.text(x, y, t, 8, True, NETS[net][0])

    s.wire([(116, 128), (150, 128)], "5V"); lab(116, 122, "USB", "5V")
    # 12 V goes to the RAMPS '5A' terminal (not the pigtail block below it)
    s.wire([(116, 300), (134, 300), (134, 268), (150, 268)], "12V"); lab(116, 294, "12 V", "12V")
    s.wire([(221, 162), (221, 178)], "CTRL")
    s.wire([(292, 220), (316, 220)], "CTRL"); lab(282, 214, "STEP", "CTRL")
    s.wire([(452, 220), (468, 220)], "MOTOR")
    s.wire([(221, 286), (221, 306)], "UART")
    s.wire([(300, 306), (300, 298), (380, 298), (380, 294)], "UART")
    # the key motor's own cable: key turner -> RAMPS E0 motor header (the only inter-unit wire)
    s.wire([(608, 220), (648, 195)], "MOTOR")
    s.text(628, 180, "~1 m cable", 8, True, NETS["MOTOR"][0], anchor="c")

    y = 410
    s.text(24, y, "Sheets", 10, True)
    s.para(24, y + 15, ["1  Overview (this sheet)", "2  Power: 12 V, 5 V, GND",
                        "3  Drivers A and B on the RAMPS", "4  Driver C and the key driver (E0)",
                        "5  Driver taps (DIAG, RX), orientation, key cable",
                        "6  Mega + RAMPS headers, UART pigtail", "7  Pin map, jumpers, currents, parts"], 8)
    s.text(300, y, "Rules", 10, True)
    s.para(300, y + 15, ["Make every connection with power off (USB unplugged, 12 V off).",
                         "Never plug or unplug a motor with 12 V on (the key motor cable included).",
                         "Power up: USB first, then 12 V. Power down: 12 V first.",
                         "Never fit an MS3 jumper: on the V1.3 that pin is the UART line.",
                         "Emergency stop: pull the 12 V plug.  `!` aborts a move.",
                         "VERIFY = not yet checked on the bench (control/bringup.md).",
                         "Rev 2026-10-08.1: key driver in E0. Rev 2026-10-08.2: UART pigtail, no hub.",
                         "If this disagrees with control/wiring.md, wiring.md wins."], 8)
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

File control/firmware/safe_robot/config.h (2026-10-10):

// ============================================================================
// config.h — EVERY value that isn't measured yet lives here, in one block.
// Each one says where it came from and which bench stage
// (control/bringup.md) measures it. Bench values can be tried live with the
// serial `set` command (RAM only) and then copied here.
//
// Units: "full steps" are motor full steps (200/rev assumed, see below);
// rps = motor revolutions per second; deci = tenths of a degree.
// Dial "away" = turning away from the dial's home stop. Key "+" = clockwise
// seen from in front of the safe (the way the key unlocks).
// ============================================================================
#pragma once

// ---- Motor and drivetrain --------------------------------------------------
// 1.8 deg/step (200/rev): confirmed in bench stage 2 (one commanded rev = one
// turn, Paul 2026-10-10).
#define CFG_FULL_STEPS_PER_REV   200
#define CFG_MICROSTEPS           16     // MRES over UART; interpolated to 256 by the driver
#define CFG_DIAL_GEAR            2      // 14T pinion -> 28T dial gear (cad/dial_unit_housing.scad)
#define CFG_KEY_GEAR             1      // key turner is direct drive
#define CFG_POSITIONS            20     // positions per dial wheel: 20 clicks per turn (Paul, 2026-10-06)

// Drivers fitted: A=1, B=2, C=4, key=8. 15 = all (needed for `start`). Bench
// stages with fewer drivers use `set axes <mask>` instead of editing this.
#define CFG_AXES_MASK            15

// ---- Directions: dials measured (stage 4b.1, Paul 2026-10-10); key: stage 5 --
// 1 = flip the motor direction. Dials: set so that a positive jog turns the
// dial CLOCKWISE seen from the front. That is away from the home stop: every
// dial turns clockwise without limit and stops only anticlockwise (Paul,
// 2026-10-06). Key: set so that a positive jog turns the key CLOCKWISE (the
// way it opens). The dial motors turn opposite to the dials (external
// gears), so the three dials probably share one value.
// Bench 4b.1 (Paul, 2026-10-10): with 0, a positive jog turned the motor
// clockwise and every dial ANTICLOCKWISE (towards its stop), all three alike.
#define CFG_INVERT_A             1
#define CFG_INVERT_B             1
#define CFG_INVERT_C             1
#define CFG_INVERT_KEY           0

// ---- Currents (control/wiring.md §7) ---------------------------------------
#define CFG_DIAL_RUN_MA          1000   // ~1 A RMS until the dial torque is measured
#define CFG_DIAL_HOLD_PCT        50
#define CFG_KEY_RUN_MA           600    // start; stage 5 sets it to 2x the measured minimum
#define CFG_KEY_HOLD_PCT         50
#define CFG_SEAT_MA              600    // lower current while seating the plugs

// ---- Speeds ------------------------------------------------------------------
// StallGuard4 needs speed: below ~0.3 rev/s this motor gives too little back
// EMF (datasheet §11.5 rule of thumb, with 0.55-0.59 N.m / 2 A / ~1.4 ohm —
// the resistance is from a vendor listing, not confirmed). 1 rev/s is ~3x
// that. Tune in bench stage 3.
#define CFG_DIAL_RPS             1.0f
#define CFG_KEY_RPS              1.0f
#define CFG_START_RPS            0.15f
#define CFG_ACCEL_RPS2           5.0f   // dials
#define CFG_KEY_ACCEL_RPS2       20.0f  // key: direct drive, light; reaches cruise within ~5 full steps,
                                        // so its short moves have cruise-speed StallGuard readings
#define CFG_SEAT_RPS             0.1f   // slow, so the plug can drop into the star (stage 4)
#define CFG_SG_MIN_RPS           0.4f   // DIAG only enabled above this speed (TCOOLTHRS)
#define CFG_STALL_IGNORE_FULL    2      // ignore DIAG for the first full steps of a move

// ---- StallGuard thresholds ---------------------------------------------------
// With CFG_SG_AUTOCAL = 1 (default) these are only a fallback: every session
// measures each motor's free-running load and sets its own threshold, and the
// last calibration is kept in EEPROM. Without autocal: 0 = not tuned, so
// `start`, `resume` and homing refuse to run. Higher = more sensitive (stall
// when SG_RESULT <= 2*SGTHRS, datasheet §5.3).
#define CFG_SGTHRS_A             0
#define CFG_SGTHRS_B             0
#define CFG_SGTHRS_C             0
#define CFG_SGTHRS_KEY           0
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

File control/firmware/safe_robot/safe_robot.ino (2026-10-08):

// Fichet-Bauche "Complice" combination robot — Arduino Mega 2560 + RAMPS 1.4.
//
//   control/firmware/README.md  build, flash, commands, log format
//   control/bringup.md          bench bring-up, stage by stage
//   control/wiring.md           pin map and harness
//   config.h                    every value not yet measured, in one place
//
// Libraries: TMCStepper 0.7.3 (Arduino Library Manager, by teemuatlut);
// SoftwareSerial, SPI and EEPROM (used in hw_mega.cpp) come with the Arduino AVR core.
#include <SPI.h>
#include <SoftwareSerial.h>
#include <TMCStepper.h>

#include "config.h"
#include "hw_mega.h"
#include "pins.h"
#include "src/core/robot.h"
#include "src/core/settings_from_config.h"

#define FW_VERSION "0.4 (2026-10-08, rev 2026-10-08.1)"

core::Settings g_settings = core::makeSettings();
HwMega g_hw(g_settings);
core::Robot g_robot(g_hw, g_settings);

void setup() {
  Serial.begin(CFG_USB_BAUD);
  g_hw.begin();
  Serial.println(F("# Fichet safe robot " FW_VERSION " - type help"));
  g_robot.boot();
}

void loop() {
  char line[64];
  if (g_hw.readLine(line, sizeof(line))) g_robot.handleLine(line);
  if (g_hw.takeAbort()) g_robot.abort();
  if (g_hw.takeButtonPress()) {
    // Button: pause a run in progress; otherwise resume a stored run, or start one.
    if (g_robot.busy()) g_robot.requestPause();
    else if (g_robot.progress().state == core::RUN_ACTIVE) g_robot.handleLine("resume");
    else if (g_robot.progress().state == core::RUN_NONE) g_robot.handleLine("start");
  }
  g_robot.tick();
  g_hw.updateLed(g_robot.state());
}

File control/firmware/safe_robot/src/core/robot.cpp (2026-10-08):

#include "robot.h"

#include <stdlib.h>
#include <string.h>

#ifdef __AVR__
#define TOKEQ(tok, lit) (strcmp_P((tok), PSTR(lit)) == 0)
#else
#define TOKEQ(tok, lit) (strcmp((tok), (lit)) == 0)
#endif

namespace core {

namespace {
const char kAxisChar[AX_COUNT] = {'A', 'B', 'C', 'K'};
// Expected (MS1, MS2) strapping per axis: UART addresses 0..3 (wiring.md §2).
const bool kMs1[AX_COUNT] = {false, true, false, true};
const bool kMs2[AX_COUNT] = {false, false, true, true};

int32_t iabs(int32_t v) { return v < 0 ? -v : v; }

bool parseAxis(const char* t, Axis* ax) {
  if (!t || !t[0] || t[1]) return false;
  const char ch = (char)(t[0] & ~0x20);  // upper case
  for (uint8_t i = 0; i < AX_COUNT; ++i)
    if (kAxisChar[i] == ch) { *ax = (Axis)i; return true; }
  return false;
}

void sort3(int32_t* v, uint8_t n) {  // insertion sort, n is small
  for (uint8_t i = 1; i < n; ++i)
    for (uint8_t j = i; j > 0 && v[j] < v[j - 1]; --j) { int32_t t = v[j]; v[j] = v[j - 1]; v[j - 1] = t; }
}
}  // namespace

uint32_t positionHash(const Settings& s) {
  uint32_t h = 2166136261u;  // FNV-1a
  auto mix = [&h](uint32_t v) { for (uint8_t i = 0; i < 4; ++i) { h ^= (v >> (8 * i)) & 0xFF; h *= 16777619u; } };
  mix(s.fullStepsPerRev); mix(s.microsteps); mix(s.dialGear); mix(s.positions);
  mix(s.detentAutocal);
  for (uint8_t d = 0; d < 3; ++d) {
    mix(s.ax[d].invert);
    mix(s.dialHome[d]);
    if (!s.detentAutocal) mix((uint32_t)(int32_t)s.homeOffsetFull[d]);  // else measured each session
  }
  return h;
}

Robot::Robot(Hal& hal, Settings& s) : hal_(hal), s_(s), journal_(hal, 0, 16), calStore_(hal) { resetOffsets(); }

void Robot::resetOffsets() {
  for (uint8_t d = 0; d < 3; ++d) {
    offsetUs_[d] = (int32_t)s_.homeOffsetFull[d] * s_.microsteps;
    notchOk_[d] = false;
  }
}

// ---------------------------------------------------------------- boot
void Robot::boot() {
  if (!journal_.load(prog_)) prog_ = Progress();
  Line l;
  l.p(CP("EV,")).u(hal_.millis()).p(CP(",BOOT,")).u(prog_.state);
  emit(l);
  if (calStore_.load(cal_) && s_.sgAutocal) {
    for (uint8_t a = 0; a < AX_COUNT; ++a)
      if (cal_.sgthrs[a]) s_.ax[a].sgthrs = cal_.sgthrs[a];
    l.clear();
    l.p(CP("# last calibration loaded: sgthrs A/B/C/K = ")).u(cal_.sgthrs[0]).c('/').u(cal_.sgthrs[1]).c('/')
        .u(cal_.sgthrs[2]).c('/').u(cal_.sgthrs[3]);
    emit(l);
  }
  printStatus();
  if (prog_.state == RUN_ACTIVE) {
    l.clear(); l.p(CP("# run in progress: next index ")).u(prog_.nextIndex)
        .p(CP(", last re-check at ")).u(prog_.verifiedIndex).p(CP(". Send `resume` (or press the button)."));
    emit(l);
  } else if (prog_.state == RUN_SUCCESS) {
    const Combo c = comboAt(prog_.successIndex, s_.positions);
    l.clear(); l.p(CP("# SUCCESS recorded at index ")).u(prog_.successIndex).p(CP(": dials "))
        .u(c.d[0] + 1).c('-').u(c.d[1] + 1).c('-').u(c.d[2] + 1).p(CP(" (from home). `reset yes` to clear."));
    emit(l);
  }
}

// ---------------------------------------------------------------- commands
void Robot::handleLine(const char* line) {
  char buf[64];
  strncpy(buf, line, sizeof(buf) - 1);
  buf[sizeof(buf) - 1] = 0;
  char* tok[5] = {0, 0, 0, 0, 0};
  uint8_t nt = 0;
  for (char* p = buf; *p && nt < 5;) {
    while (*p == ' ' || *p == '\t' || *p == '\r') ++p;
    if (!*p) break;
    tok[nt++] = p;
    while (*p && *p != ' ' && *p != '\t' && *p != '\r') ++p;
    if (*p) *p++ = 0;
  }
  if (nt == 0) return;
  const char* cmd = tok[0];
  Line l;

  if (TOKEQ(cmd, "status")) { printStatus(); return; }
  if (TOKEQ(cmd, "abort")) { abort(); return; }
  if (TOKEQ(cmd, "pause")) {
    if (busy()) { pauseReq_ = true; l.p(CP("# pause requested: stopping after this attempt")); emit(l); }
    return;
  }
  if (busy()) { l.p(CP("# busy: only status / pause / abort ('!') now")); emit(l); return; }
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

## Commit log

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2026-09-28 Add second height-sweep plate: 1.80-2.00mm at width 1.04mm
    1.75/1.04 still had a little play. Continuing the height trend
    upward (taller teeth have trended tighter each round) with five more
    variants on one plate: 1.80 / 1.85 / 1.90 / 1.95 / 2.00mm, width held
    fixed at 1.04mm (confirmed fine). Each labeled on the bottom of its
    handle, height on line 1 / width on line 2, same convention as the
    1.75-1.04 key.
    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
    [tube_socket_test_key_set.scad, tube_socket_test_key_set.stl]
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2026-09-29 Close out tooth geometry (2.00mm/1.04mm); adopt two-unit architecture
    - docs/decisions.md: tooth height/width locked in at 2.00mm/1.04mm
    after the second height sweep; all five felt equivalent by hand, so
    went with the tightest for wear margin. Noted PETG-CF/nylon as the
    wear mitigation for the final coupler.
    - cad/tube_socket_test_key.scad: default parameters updated to match
    (2.00/1.04).
    - control/sequence.md: replaced the single-frame mounting concept with
    two independently-mounted units (dial unit + electronics; separate
    key-turner unit for socket #4, which turned out to use a traditional
    ornate key bow rather than the spline profile). Documented driver
    placement (local t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
    [tube_socket_test_key.scad]
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2026-09-29 Add first-pass housings for the dial unit and key-turner unit
    Two OpenSCAD housings (v0.1, first pass), built per go-ahead to try
    this now with the confirmed tooth geometry ("good enough for a first
    pass") rather than wait on further key refinement:
    - cad/common_mounts.scad: shared NEMA17 bolt pattern, magnet-pocket
    (reusing the confirmed 8.00mm x 1.9mm geometry), and D-shaft
    coupler-bore modules, used by both housings.
    - cad/dial_unit_housing.scad: front registration plate with 3 coupler
    bushings + a magnet ring, a motor tier, and a first-pass electronics
    tray, all bridged into one connected static frame, plus 3 loose
    rotating dial_coupler() parts (confirmed spline tip, reused fr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
    [common_mounts.scad, dial_unit_housing.scad, dial_unit_housing.stl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]
2026-09-29 Replace bought flex coupler with a printed Oldham coupler (v0.2)
    Per discussion: the dial unit's motor-to-coupler offset (NEMA17 bodies
    too big to sit directly behind the real, tightly-spaced dial holes)
    was originally going to be bridged with an off-the-shelf 5mm-5mm
    flexible shaft coupler. Switched to a printed Oldham coupler instead —
    three rigid pieces (two slotted hubs + a sliding middle disc) that
    absorb the offset by sliding, not by flexing. A bought bellows/helical
    coupler works by elastically flexing every cycle, which is a poor fit
    for PETG given the dial motors' cycle count over an 8,000-combination
    search; a rigid sliding joint doesn't have that fatigue exposure.
    - common_moun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
    [common_mounts.scad, dial_unit_housing.scad, dial_unit_housing.stl]
2026-09-29 Split dial-unit housing into two bolt-together assemblies (v0.3)
    frame() fused front_plate + motor_plate + electronics_tray into one
    printed object, connected only by 3 thin pillars and a bridge arm
    across the ~20mm rear_standoff gap. Bambu Studio flagged the result as
    an unsupported bridge: with front_plate on the bed, motor_plate (and
    the tray beyond it) was a large flat disc floating between 3 posts
    spaced ~50mm apart.
    Replace frame() with front_assembly() (front_plate + 3 standoff legs)
    and rear_assembly() (motor_plate + bridge_arm + electronics_tray) as
    two independently self-supporting parts that bolt together after
    printing via M3 screws into heat-set inserts at the same 3 corner
    pos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
    [dial_unit_housing.scad]
2026-09-29 Regenerate dial_unit_housing.stl for the v0.3 split assemblies
    The tracked STL export was left stale after the v0.3 change
    (461c0ca) — it still had the old single fused frame() body. Re-export
    from the current .scad so the tracked STL matches front_assembly() +
    rear_assembly() + the 9 loose drivetrain parts (11 disconnected,
    watertight components, verified with trimesh).
    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
    [dial_unit_housing.stl]
2026-09-30 Move electronics mounting onto its own standoff tier (v0.4)
    Paul printed the v0.3 STL: the electronics_tray needed supports (still
    cantilevered off motor_plate via a single bridge_arm) and, worse,
    physically fouls one of the 3 dial motors once printed.
    Root cause: electronics_tray sat only 4mm proud of motor_plate's outer
    face, but that's also the face the NEMA17 motors bolt to (their can
    extends outward from there, not into the rear_standoff cavity). The
    housing never modeled the motor's real body length -
    nema17_body_clearance() is a deliberate 0.1mm face-clearance pocket,
    not the actual ~48mm can. Looked up rather than guessed: the exact
    ordered STEPPERONLINE 55Ncm/2A part is listed at 4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
    [dial_unit_housing.scad, dial_unit_housing.stl]
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2026-10-02 Correct bolt-together screw length to M3x8 (was wrongly M3x10/M3x12)
    Checked precisely rather than repeating the earlier estimate, since
    Paul's about to do a real test assembly. Both joints have a 3.2mm
    counterbore and a 6mm-deep insert bore in the leg, but the plate
    material between them differs: 2.8mm for the front-to-rear joint
    (motor_plate, 6mm) vs only 1.8mm for rear-to-deck (electronics_deck,
    5mm). That caps usable screw length before the tip bottoms on the
    leg's solid floor before the head seats flush: ~8.8mm front, ~7.8mm
    deck. M3x10/x12 would leave the deck joint proud instead of clamped.
    M3x8 clears both ceilings with a standard ~5mm M3 heat-set insert.
    Updated the print notes in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
    [dial_unit_housing.scad]
2026-10-02 Fix key-turner's missing motor shaft hole; fix dead set-screw hole
    Paul printed all parts for a first test assembly. The dial unit looked
    fine; the key-turner didn't - no way for the motor to actually reach
    or drive the gripper. Checked by reading the code rather than
    guessing, and found two real gaps:
    1. key_turner_housing.scad's frame() bolted the motor to a boss but
    never cut a shaft hole through it - only the bolt holes and magnet
    ring were ever subtracted. The shaft would have driven straight
    into solid plastic. Fixed by adding a clearance hole through the
    full plate+boss depth, and checked it closes against the real
    motor's 24mm shaft protrusion with ~3mm of spacer budg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
    [common_mounts.scad, dial_unit_housing.stl, key_turner_housing.scad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]
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2026-10-02 Add printed internal thread fit test (real ISO thread, not self-tap)
    standoff_screw_fit_test.scad answered "which on-hand screw self-taps
    into the existing hole" — this answers a different question: can a
    real M5/M6 screw thread directly into a printed ISO-profile thread
    with no self-tapping and no insert. Sweeps +0.0/+0.2/+0.4mm diametral
    clearance per size to find what a given printer/filament needs.
    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
    [printed_thread_test.scad, printed_thread_test.stl]
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2026-10-03 Rework motor sled fit: reorient motors, switch deck standoffs to M5 self-tap
    Bench fit (Paul, 2026-10-03) found a motor can fouls a deck standoff
    leg at the default orientation. Fix: rotate each motor about its own
    shaft axis (motor_rotation = [40,70,10], found by a 2D collision
    search over the real 42.3mm NEMA17 can vs. the legs and the other
    motors) rather than translate it, so the shaft stays centered.
    Documented honestly in housing_decisions.md: the idealized sharp-
    square model's own best case is still ~-1.17mm, i.e. a genuinely
    tight fit, not a clean margin — trusting Paul's real printed/bolted
    bench test over the idealized model rather than growing
    motor_min_spacing (which would cas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
    [dial_unit_housing.scad, dial_unit_housing.stl]
2026-10-03 Fix deck-standoff/motor crowding, add NEMA17 boss recess, use real Mega hole pattern
    Three real bench-fit problems from Paul's second physical test of
    rear_assembly() + the deck-to-electronics joint:
    - deck_standoff_legs() were crowding 2 of 3 motors badly enough they
    couldn't seat or have their screws reached. Re-ran the same
    brute-force 2D clearance sweep used for the earlier motor_rotation
    fix and moved deck_leg_r 28mm -> 46mm (+4.8mm/+8.8mm worst-case
    margin to motor body/bolt holes, up from an actual -1.8mm overlap).
    plate_outline() grew an opt-in pad_deck_legs hull padding so
    motor_plate()'s edge follows, sized to Paul's own "1mm from the
    edge" request.
    - The real motor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
    [common_mounts.scad, dial_unit_housing.scad, dial_unit_housing.stl]
2026-10-03 Confirm NEMA17 dimensions against the real motor's manufacturer drawing
    Paul identified the exact motor on hand (STEPPERONLINE 17HE19-2004S)
    and cross-checked its dimensional drawing against the real part with
    calipers. Every existing NEMA17 figure in common_mounts.scad checks
    out, including the 22mm x 2mm pilot boss from the previous commit
    (measured with no vendor drawing available at the time, now exactly
    confirmed by this one). Tightened nema17_bolt_square from a generic
    31.04mm "typical" figure to the drawing's own 31mm nominal (both are
    inside the drawing's +/-0.2mm tolerance, this just cites the real
    source instead of a generic one). Also corrected dial_unit_housing.scad's
    can-length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
    [common_mounts.scad, dial_unit_housing.scad, dial_unit_housing.stl]
2026-10-03 Make dialer base a 150mm circle, relocate front-to-rear joint off the motors
    The front-to-rear M3+insert joint (plate_corner_pts, now joint_pts) sat
    at the same 3 angles as the motors themselves, just farther out along
    the same ray - harmless until the earlier motor-rotation fix rotated
    each motor's body-clearance square into reaching that far. Paul's
    bench report: "there are no standoff holes to attach the dialer base
    ... the old holes were taken."
    Two changes, both requested by Paul:
    - front_plate() (the dialer base) is now a plain 150mm-diameter circle
    (front_plate_outline()), decoupled from motor_plate()'s own outline.
    - The joint moved to a swept position clear of every rotated moto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
    [dial_unit_housing.scad, dial_unit_housing.stl]
2026-10-03 Fix motor bolt holes exposed at the plate edge after the joint move
    Paul caught a regression in the previous commit: relocating joint_pts
    off the motors' own angles (to fix the joint-vs-motor-body collision)
    silently removed hull coverage the old joint position had been
    providing by coincidence, leaving one bolt hole per motor sitting
    right on motor_plate_outline()'s edge.
    Add a rotation-invariant motor_pad_r hull-padding set, centered on
    motor_pts, sized to contain the rotated motor body-clearance square at
    any rotation angle. Verified via shapely: all 12 bolt holes now clear
    the edge by 11.33mm worst case (was 0.01mm). Re-rendered and
    re-confirmed 12 watertight bodies via trimesh; the joi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
    [dial_unit_housing.scad, dial_unit_housing.stl]
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2026-10-05 WIP: dial unit v2 — geared drivetrain on 608 bearings (hole pattern still a photo estimate)
    Work in progress, not for printing yet: the door hole positions
    (dial_ab/ac/bc) are a photo estimate and will be replaced from Paul's
    higher-resolution door photos before the PR.
    - Replace the printed Oldham coupler, which could not work as modeled:
    the disc tongues were 1mm shorter than closed slots (+/-0.5mm of slide
    against the 6.9mm needed), and the 24mm motor shaft ran through the
    motor hub into the disc and the dial hub.
    - New drivetrain: per dial, a spring-loaded gear-shaft (spline plug,
    7.85mm journal, 28T m1 gear) sliding in two stacked 608 bearings,
    driven 2:1 by a 14T pinion on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
    [common_mounts.scad, dial_drivetrain.stl, dial_front_assembly.stl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]
2026-10-05 Dial unit v2: caliper hole pattern, docs, SketchUp build script
    - Door hole pattern from Paul's caliper measurements (far/near jaw
    readings averaged): 33.0mm across the top pair, 42.5mm from each to the
    bottom hole. Replaces the photo estimate. Star face 3.14mm below the
    door face, so the plug reaches 3.9mm in, the same as the hand test key.
    - All checks re-run on the measured pattern: 2D clearances, gear mesh,
    axial stack and pinion float pass; 3D interference check over 12 poses
    finds no overlap; every STL watertight.
    - Pinion D-bore starts 2.5mm in, so the end of the shaft's flat locates
    the pinion; set screw optional (grub screw only).
    - docs: v2 entry in housing_decisions.md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
    [dial_drivetrain.stl, dial_front_assembly.stl, dial_motor_sled.stl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]
2026-10-05 Dial unit v2: correct the door-hole depth records
    Paul clarified the depth readings: the star starts 3.14mm below the door
    face; the caliper depth gauge (~2mm wide) stops at 8.92mm because the
    star's slots narrow toward a point; a real key goes in to 15.5mm. The
    first write-up had 8.92 as the star's mouth width and 13.3 as the hole
    depth. Removed the two claims that rested on that: a wide star mouth
    giving the plugs radial room, and the plug being lengthenable by ~3mm.
    No geometry change: the 5mm plug (tip 7mm deep, 3.9mm into the star)
    matches the test key; tooth width stays 1.04 (Paul).
    Claude-Session: https://claude.ai/code/session_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
    [dial_unit_housing.scad]
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2026-10-06 Motor sled: M3 countersinks instead of counterbores (prints without bridging strings)
    Paul's printed sled had stringy counterbores: the sled prints inner face
    down, so each counterbore shoulder was an unsupported bridge. Now 90deg
    countersinks (7.0mm mouth, 1.8 deep) for M3x10 ISO 10642 screws: heads
    flush, 4.1mm of thread in the motor's 4.5mm-min holes (asserted).
    Layout check passes, interference check clean, STLs re-rendered,
    SketchUp build script updated to match.
    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
    [dial_motor_sled.stl, dial_unit_housing.scad, dial_unit_housing.stl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]
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2026-10-06 Motor sled: countersink mouth 6.3mm so ISO 10642 and DIN 7991 M3x10 heads both work
    Paul's kit (M3x10 x55) doesn't state the head standard. With the 7.0mm
    mouth a DIN 7991 head (dk 6.0) could sit 0.5mm deep and put 4.5mm of
    thread into the motor's 4.5mm-min holes. At 6.3mm: ISO heads 0.21mm
    proud (3.79mm engagement), DIN heads 3.95-4.15mm. All three cases are
    asserted; the assert fails on the old 7.0 value. Layout check passes,
    interference check clean, STLs re-rendered, SketchUp model rebuilt.
    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
    [dial_motor_sled.stl, dial_unit_housing.scad, dial_unit_housing.stl]
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2026-10-06 Mount both units with 22mm rubber pot magnets (Wukong) instead of 8x2 disc pockets
    - common_mounts.scad: shared rmag_* mount — through hole (no floor to string),
    seat ring OD29 to z=5.8 so the rubber stands 0.2 proud, printed retainer
    disc d27x3 clamped by an M4 screw into the magnet.
    - Dial unit: 6 magnets at r53.5 / 26.75deg (searched for leg + boss clearance);
    disc field removed. Layout check ALL PASS, interference check clean.
    - Key turner: 3 magnets at r31, 60/180/300deg; legs re-clocked to 0/120/240;
    base 6 -> 5mm. key_turner_check NO INTERFERENCE at all 15 poses.
    - print_magnet_retainer.scad (10 retainers); STLs re-rendered, watertight.
    - SketchUp build scripts: magnets + re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
    [common_mounts.scad, dial_front_assembly.stl, dial_unit_housing.scad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]
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2026-10-06 Wiring harness: pin map, resolved harness issues, cable pin-out, diagrams
    control/wiring.md settles the harness open issues from CLAUDE.md, with
    sources (Marlin pins_RAMPS.h, TMC2209 datasheet rev 1.09, BTT TMC2209 V1.3
    manual + schematic, RAMPS 1.4 KiCad netlist, TMCStepper 0.7.3):
    - one UART bus on Serial2 with a single 1k (TX2 -> 1k -> bus), addresses
    X0/Y1/Z2 by RAMPS MS1/MS2 jumpers, key 3; UART tapped at the MS3 jumper
    pin (BTT V1.3 puts PDN_UART in the MS3 position)
    - DIAG on interrupt pins D3/D2/D18 (dials) and D19 (key); the V1.3's
    down-pointing DIAG pin needs a one-time lead mod on the dial drivers
    - 6-core cable: 12V, GND, 5V (VIO from the Mega), STEP, UART, DIAG; remote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
    [harness.yml]
2026-10-06 Firmware v0.1, bench bring-up plan, and Complice lock research
    control/firmware/: Arduino Mega sketch on the PR 1 pin map.
    - src/core/ (plain C++, no Arduino): sequencer (seat -> home in two
    passes -> learn N -> serpentine attempt loop logging the key angle ->
    classify -> retract), periodic re-checks with rewind, EEPROM journal
    for resume after power loss / re-seat, TMC UART frames, step ramp
    - hw_mega: TMCStepper 0.7.3 over Serial2, own bounded step pulses, DIAG
    latched in interrupts, non-blocking SG_RESULT sampling, key direction
    via GCONF.shaft with read-back, key enable via TOFF
    - config.h: every unmeasured value in one block (directions, currents,
    speeds, StallGuard threshol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
    [config.h, hal.h, hw_mega.cpp]
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2026-10-06 Firmware/docs: Paul's dial and key checks, and the manual's normal use
    Paul, 2026-10-06: each dial turns clockwise without limit and stops
    anticlockwise, 20 clicks per turn; the key goes in one way only, can't
    turn anticlockwise from there, turns ~100 deg clockwise, comes out only
    at the start. The manual's "Normal use" (screenshot saved in docs/photos):
    dial the combination, then insert the key and turn clockwise.
    - seat routine now turns clockwise, so it can never press a plug into the
    stop (it turned toward the stop before)
    - simulator models the one-way stop; new test checks homing from both
    sides of the turn and that no move presses a stop with stall detection
    off (fails on the o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
    [config.h, robot.cpp, sim_hal.h]
2026-10-06 Firmware v0.2: self-calibration, key search after power cuts
    From Paul's answers (2026-10-06): the key stays wherever it is left; the
    clicks are evenly spaced (18 deg) but where the first sits relative to the
    stop can't be read by hand; no door marks; the manual has no warning about
    wrong combinations. Paul suggested the robot calibrate itself.
    - self-calibration every session (and as a `calibrate` command): each
    dial makes one free clockwise turn; its lowest binned StallGuard
    reading sets the threshold (stall at 50 % of it, datasheet 11.4), and
    the 18-deg click ripple's fundamental gives the click positions, so
    position 1 = first click clockwise of the stop. The key is measured ove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
    [config.h, hal.h, hw_mega.cpp]
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2026-10-06 Record Paul's answers: Mac, slicer defaults, M6x16 on the key turner, springs ordered
    - Mac confirmed: the manual drops its Mac assumption.
    - Slicer: Bambu Studio's default H2D settings for every part so far
    (manual §1.1, housing log).
    - Key turner plate-to-leg screws are M6x16, not M6x20: Paul has both
    and found 16 mm works better (6 mm plate + 10 mm in the 16 mm pilot,
    as on the dial unit). Manual, BOM, housing log (with a correction note
    on the v1 entry) and the print note in key_turner_housing.scad. The
    SCAD change is a comment only; no geometry or STL changes.
    - Springs: ordered, arriving 2026-10-07 (manual, BOM, README).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
    [key_turner_housing.scad]
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2026-10-07 Schematic: fixes from an independent check against wiring.md
    An independent review compared every connection on the 7 sheets with
    control/wiring.md: no wrong connections. Fixed what it flagged:
    - Sheet 5: interrupt pins were labelled "INT1" etc. with Arduino
    attachInterrupt numbers, which read as the ATmega2560's INTn names
    (D2 = INT4, D3 = INT5, D18 = INT3, D19 = INT2). Now "(irq)" with the
    Arduino numbers spelled out in the notes.
    - Sheet 1: the power rule now matches wiring.md §8 (all connections
    with USB and 12 V off; never plug a motor or the cable with 12 V on).
    - Sheets 6, 7: added wiring.md §6.1's VERIFY (INDEX/DIAG on the 2.54 mm
    grid before soldering the remote board's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
    [schematic.py]
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2026-10-07 Parts ordered; 1.6 A glass fuse stands in for hub F1 until the PTC arrives
    Paul placed the amazon.fr order (items 1, 2 and 5-8). No PTC listing
    arrives soon, so he ordered 1.6 A glass cartridge fuses for F1's place,
    in a holder he will print. Logged in control/wiring.md with the reasoning
    (the key branch draws < 0.6 A; 1.6 A is well under the PSU's 5 A) and
    what the holder needs: solid metal-to-metal contact, since a dropout
    resets the key driver. Fuse size and F/T are still to confirm.
    Status updated in bom.md, order_remaining_parts.md, wiring.md §5/§8/§10,
    manual §2.2/§2.6 and CLAUDE.md. Schematic rev 5: the parts table shows
    "ordered" instead of BUY, and F1 notes the interim fuse. C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
    [schematic.py]
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2026-10-07 Firmware v0.3: catch TMC2209 driver resets (GSTAT) instead of a false SUCCESS
    A TMC2209 whose 12 V (or 5 V) dips resets to its power-on registers: no
    StallGuard, current from the VREF pot, other microsteps. v0.2 never read
    GSTAT mid-session, so a key-driver reset made the next key try run open
    loop to its commanded angle and classify as SUCCESS (reproduced in the
    simulator).
    - HAL: new hook Hal::gstat(Axis); HwMega reads GSTAT over UART (no reply
    = 0x80).
    - Core: GSTAT of the moving driver before and after every move, all
    fitted drivers before every attempt (and bench `try`), and a driver
    already set up before configure() re-writes it (which clears GSTAT).
    A flag logs GSTAT,ms,axis,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
    [hal.h, hw_mega.cpp, logger.py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]
2026-10-07 Every driver's VREF pot to minimum: Paul agreed
    Recorded in the wiring decision log (2026-10-07) and carried into
    wiring §8 step 2, manual 2.9 (the pots matter after a driver reset)
    and schematic sheet 7's power-order notes (PDF regenerated; only that
    line changed).
    Claude-Session: https://claude.ai/code/session_014hPACJWBSidqqHhftwCEqJ
    [schematic.py]
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2026-10-07 Magnet hole fit-test strip (21.4-21.8mm): the 21.5mm magnets fall out of the 22.4mm holes off the door; correct manual
    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
    [magnet_fit_test.stl, print_magnet_fit_test.scad]
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2026-10-07 Magnet holes 21.7mm (from the fit test) on both plates; PLA wrap strips; snug-fit fitting steps
    - common_mounts.scad: rmag_d 21.5 (measured), rmag_hole_d 21.7 (Paul's fit
    test: snug at 21.8, worked in at 21.7).
    - Re-rendered dial_front_assembly.stl, key_turner_base.stl and the two
    whole-unit STLs; watertight; holes measured 21.70 by slicing. Layout check
    ALL PASS; dial and key-turner interference checks NO INTERFERENCE.
    - SketchUp build scripts: magnet and hole radii updated (models not rebuilt).
    - magnet_wrap_strips.stl: 69 x 5mm PLA strips, 1/2/3 layers, to wrap a
    magnet in the old 22.4mm holes.
    - Manual 1.3a: with a snug hole the magnet is pressed in from the door side,
    plate in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
    [common_mounts.scad, dial_front_assembly.stl, dial_unit_housing.stl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]
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2026-10-08 Revision 2026-10-08.1: move the key driver onto the RAMPS (E0 socket)
    Paul's call: the key's TMC2209 goes in the empty RAMPS E0 socket beside the
    three dial drivers, and the key motor's own ~1 m cable plugs into the E0
    motor header. The original "driver next to its motor" rationale (StallGuard
    near the motor) had no source and contradicts normal sensorless-homing
    practice; withdrawn.
    Removed: the remote driver board (and its CAD mount to-do), the 6-conductor
    inter-unit cable + Phoenix connectors, the hub's 12 V branch + fuse (PTC and
    the interim glass-fuse holder), and the remote board's two 100 uF caps. The
    hub board is now just the UART junction (R1 + the bus node).
    Firmware v0.4: the ke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
    [hal.h, harness.yml, hw_mega.cpp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]
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
